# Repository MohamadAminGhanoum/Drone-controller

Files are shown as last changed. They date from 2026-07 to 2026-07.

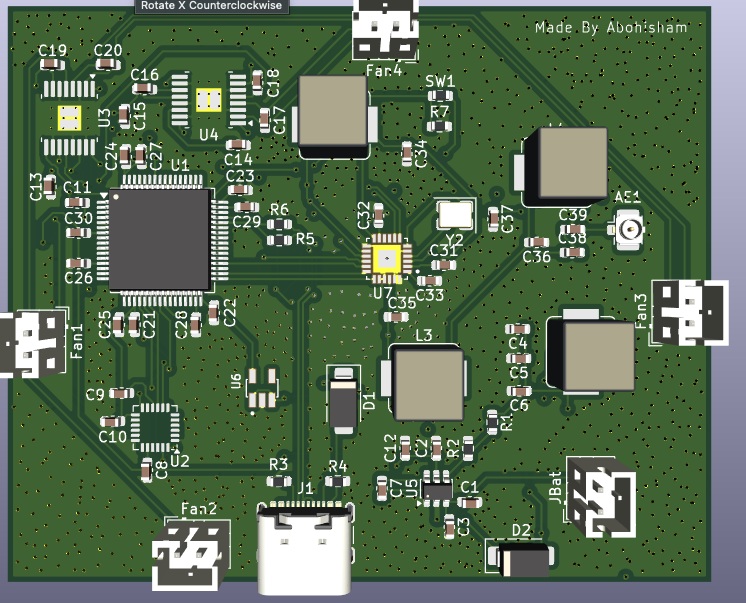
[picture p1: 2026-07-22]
ASSETS_Drone_controller/Screenshot 2026-07-12 at 15.29.26.png

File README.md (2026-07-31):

# Drone-controller
So i have this drone that i have had for a very long time. I recieved it without a controller, so it was basically a uselss drone. I played with it previously and tried to connect all 4 motors to 5v to see if it would fly, but ofc it wouldnt stablilize and all that. Today i know that i need a specific IMU snesor using the gyroscope to determing how the drone is positioned, and then it would send this signal to a chip that would control the current or power recieved by each motor to stabilize the drone. This is what i have planned to make in this project, and it would be slightly more complex than a normal drone controller, as i need to add motor controllers as well because my drone has bruhless motors.

## Schematics for controller:



## Schematics for remote:



## PCB for controller:



## PCB for remote:



## 3d shape for controller:



## 3d shape for remote:


## BOM:

|Nr |Designator |Footprint |Quantity |Cost, usd|Designation |Supplier and ref|Link |
|---|---|---|---|---|---|---|---|
|1  |U1 |LQFP-64_10x10mm_P0.5mm |3 |20.86 |STM32F405RGTx |Lcsc |https://www.lcsc.com/product-detail/C15742.html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 |
|2  |Fan1,2,3,4 |JST_PH_B2B-PH-K_1x02_P2.00mm_Vertical |20 |0.71 |MOTORs |LCSC |https://www.lcsc.com/product-detail/C131337.html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 |
|3  |R5,R6 |R_0603_1608Metric |100 |0.72 |22 |LCSC |https://www.lcsc.com/product-detail/C107701.html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 |
|4  |L2 |L_Bourns_SRP7028A_7.3x6.6mm |10 |0.8 |15uH |LCSC |https://www.lcsc.com/product-detail/C5349699.html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 |
|5  |C3,C32,C10,C17,C30,C18,C21,C23,C20,C9,C29,C26,C22,C19,C7,C24,C25|C_0603_1608Metric |50 |1.27 |0.1uF |LCSC |https://www.lcsc.com/product-detail/C14663.html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 |
|6  |C31,C33 |C_0603_1608Metric |50 |0.8 |10nF |LCSC |https://www.lcsc.com/product-detail/C100042.html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 |
|7  |U7 |XCVR_SX1280IMLTRT |3 |12.71 |SX1280IMLTRT |LCSC |https://www.lcsc.com/product-detail/C125969.html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 |
|8  |C39 |C_0603_1608Metric |50 |0.73 |100pF |LCSC |https://www.lcsc.com/product-detail/C14665.html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 |
|9  |C34 |C_0603_1608Metric |20 |0.62 |470nF |LCSC |https://www.lcsc.com/product-detail/C1623.html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 |
|10 |C2,C1,C12,C15 |C_0603_1608Metric |20 |0.83 |10uF |LCSC |https://www.lcsc.com/product-detail/C19702.html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 |
|11 |C6,C4,C5 |C_0603_1608Metric |5 |0.66 |22uF |LCSC |https://www.lcsc.com/product-detail/C2762594.html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|
|12 |U5 |SOT-23-6 |3 |4 |TPS563200 |LCSC |https://www.lcsc.com/product-detail/C97253.html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 |
|13 |C35 |C_0603_1608Metric |5 |0.76 |0.8pF |LCSC |https://www.lcsc.com/product-detail/C42432054.html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 |
|14 |U4,U3 |HTSSOP-16-1EP_4.4x5mm_P0.65mm_EP3.4x5mm_Mask2.46x2.31mm_ThermalVias|3 |3.27 |DRV8833PWP |LCSC |https://www.lcsc.com/product-detail/C50506.html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 |
|15 |J1 |USB_C_Receptacle_GCT_USB4105-xx-A_16P_TopMnt_Horizontal |2 |0 |USB_C_Receptacle_USB2.0_16P|Selfsourced |previously bought from lcsc |
|16 |C16,C11 |C_0603_1608Metric |50 |0.8 |0.01uF |LCSC |https://www.lcsc.com/product-detail/C100042.html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 |
|17 |C13,C14,C28 |C_0603_1608Metric |50 |1.45 |2.2uF |LCSC |https://www.lcsc.com/product-detail/C23630.html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 |
|18 |R3,R4 |R_0603_1608Metric |100 |0.28 |5.1k |LCSC |https://www.lcsc.com/product-detail/C2907044.html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 |
|19 |R7,R2 |R_0603_1608Metric |100 |0.81 |10k |LCSC |https://www.lcsc.com/product-detail/C844918.html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 |
|21 |C27 |C_0603_1608Metric |50 |1.15 |1uF |LCSC |https://www.lcsc.com/product-detail/C29936.html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 |
|22 |D1,D2 |D_SMA |50 |0.73 |SS14 |LCSC |https://www.lcsc.com/product-detail/C2837270.html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 |
|23 |C38 |C_0603_1608Metric |100 |0.72 |0.5pF |LCSC |https://www.lcsc.com/product-detail/C1633.html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 |
|24 |Y2 |Crystal_SMD_3225-4Pin_3.2x2.5mm |5 |0.51 |52mhz |LCSC |https://www.lcsc.com/product-detail/C3034316.html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 |
|25 |AE1 |U.FL_Hirose_U.FL-R-SMT-1_Vertical |1 |N/A |Antenna |N/A |https://www.lcsc.com/product-detail/C88374.html |
|26 |JBat |JST_PH_B2B-PH-K_1x02_P2.00mm_Vertical |20 |0.71 |Battery_connector |LCSC |https://www.lcsc.com/product-detail/C131337.html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 |
|27 |L1 |L_Bourns_SRP7028A_7.3x6.6mm |10 |0.7 |3.3uH |LCSC |https://www.lcsc.com/product-detail/C5349703.html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 |
|28 |R1 |R_0603_1608Metric |100 |0.32 |54.9k |LCSC |https://www.lcsc.com/product-detail/C23077.html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 |
|29 |SW1 |R_0603_1608Metric |1 |0 |SW_Push |Selfsourced |previously bought from lcsc |
|30 |U6 |SOT95P285X140-5N |5 |0.79 |AP2112K-3.3TRG1 |LCSC |https://www.lcsc.com/product-detail/C51118.html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 |
|31 |U2 |InvenSense_QFN-24_4x4mm_P0.5mm |2 |29.24 |MPU-6000 |LCSC |https://www.lcsc.com/product-detail/C92401.html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 |
|32 |C8 |C_0603_1608Metric |50 |0.63 |2.2nF |LCSC |https://www.lcsc.com/product-detail/C16033.html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 |
|33 |C37,C36 |C_0603_1608Metric |100 |0.68 |1.2pF |LCSC |https://www.lcsc.com/product-detail/C519098.html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|
|34 |PCB |Remote controller |5 |7 |N/A |Jlcpcb |N/A |
|35 |PCB |Drone controller |5 |7 |N/A |Jlcpcb |N/A |
|36 |AE1 |Antenna |2 |6.43 |N/A |LCSC |https://www.lcsc.com/product-detail/C3285086.html |
|37 |C |C_0603_1608Metric |50 |0.7 |15pf |LCSC |https://www.lcsc.com/product-detail/C1644.html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 |
| | | | | | | | |
| | | |Total price w. tax & ship|150.69 | | | |

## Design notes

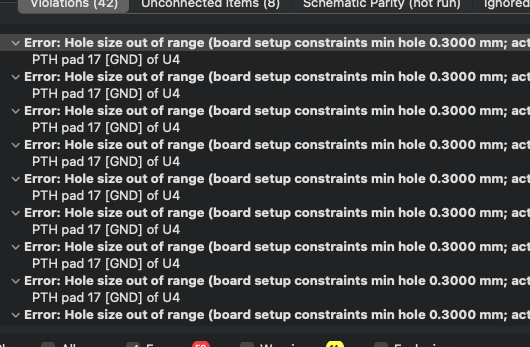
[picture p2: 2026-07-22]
ASSETS_Drone_controller/Screenshot 2026-07-12 at 12.57.38.png

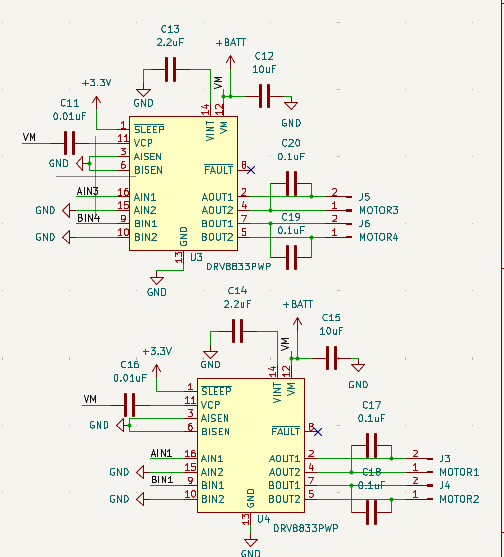
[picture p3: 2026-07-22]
ASSETS_Drone_controller/Screenshot 2026-07-10 at 17.01.51.png

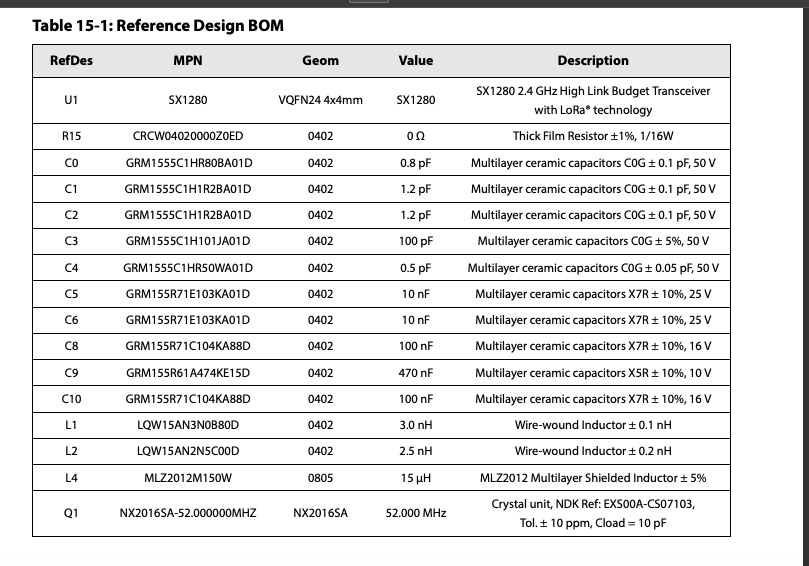
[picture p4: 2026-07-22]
ASSETS_Drone_controller/Screenshot 2026-07-10 at 17.49.38.png

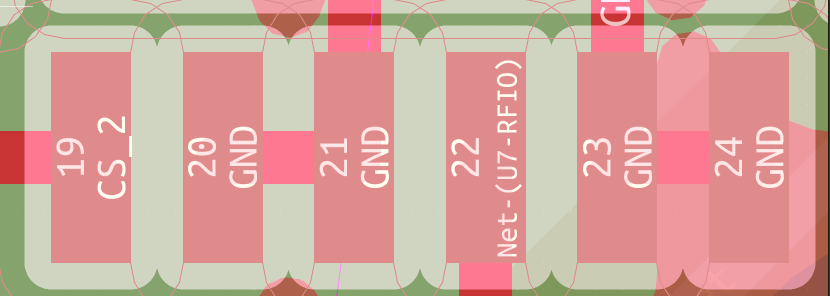
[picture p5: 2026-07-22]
ASSETS_Drone_controller/Screenshot 2026-07-12 at 13.29.08.png

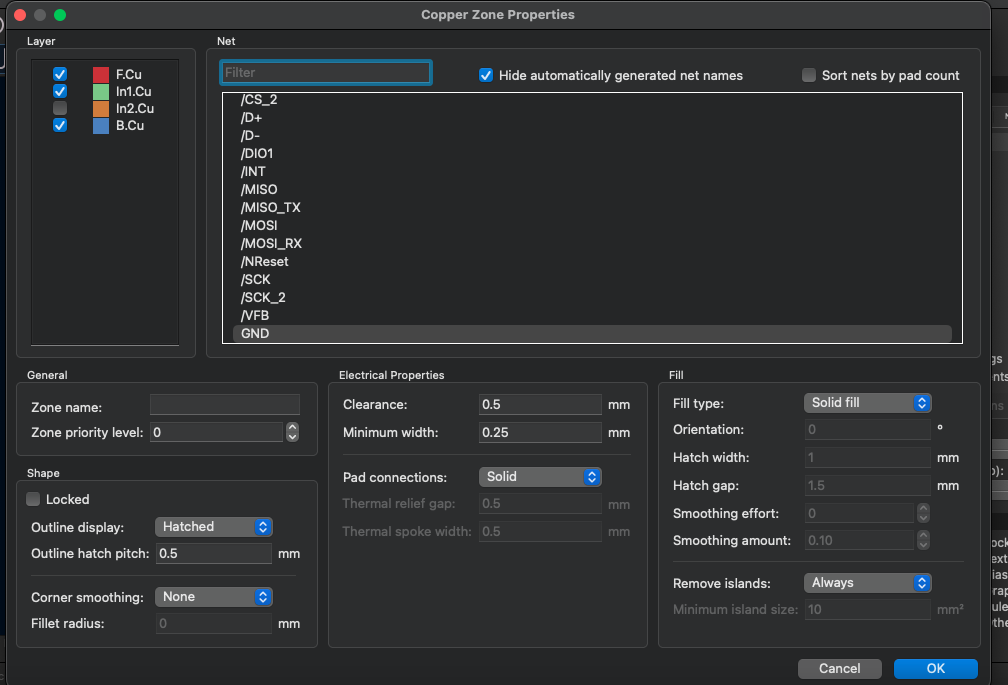
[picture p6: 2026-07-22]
ASSETS_Drone_controller/Screenshot 2026-07-12 at 12.56.29.png

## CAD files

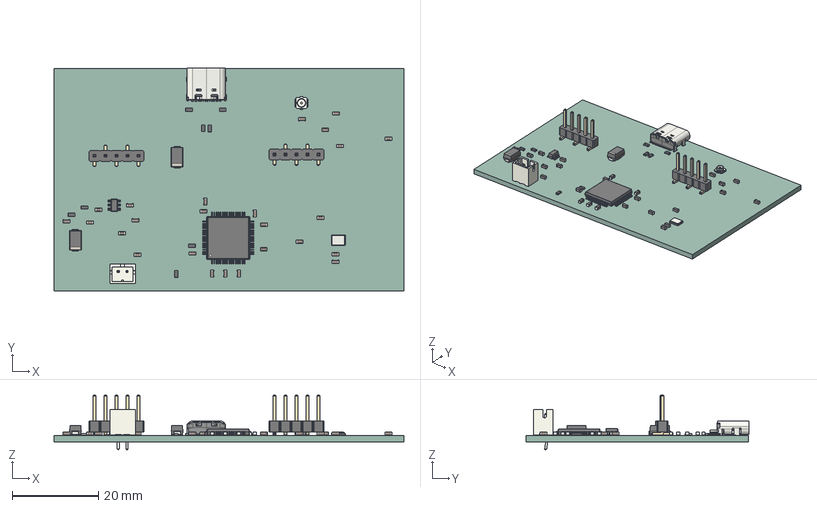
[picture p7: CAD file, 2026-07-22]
ASSETS_Drone_controller/Remote control.step
81.1 x 51.6 x 12.7 mm
Crystal_SMD_3225-4Pin_3.2x2.5mm
R_0603_1608Metric x 8
C_0603_1608Metric x 25
D_SMA x 2
PinHeader_1x05_P2.54mm_Vertical_SMD_Pin1Left
JST_PH_B2B-PH-K_1x02_P2.00mm_Vertical
LQFP-64_10x10mm_P0.5mm
USB_C_Receptacle_GCT_USB4105-xx-A_16P_TopMnt_Horizontal
U.FL_Hirose_U.FL-R-SMT-1_Vertical
SOT-23-6
PinHeader_1x05_P2.54mm_Vertical_SMD_Pin1Right
Remote control_PCB

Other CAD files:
CAD/Remote control CAD.step
CAD/Remote control CAD.f3z

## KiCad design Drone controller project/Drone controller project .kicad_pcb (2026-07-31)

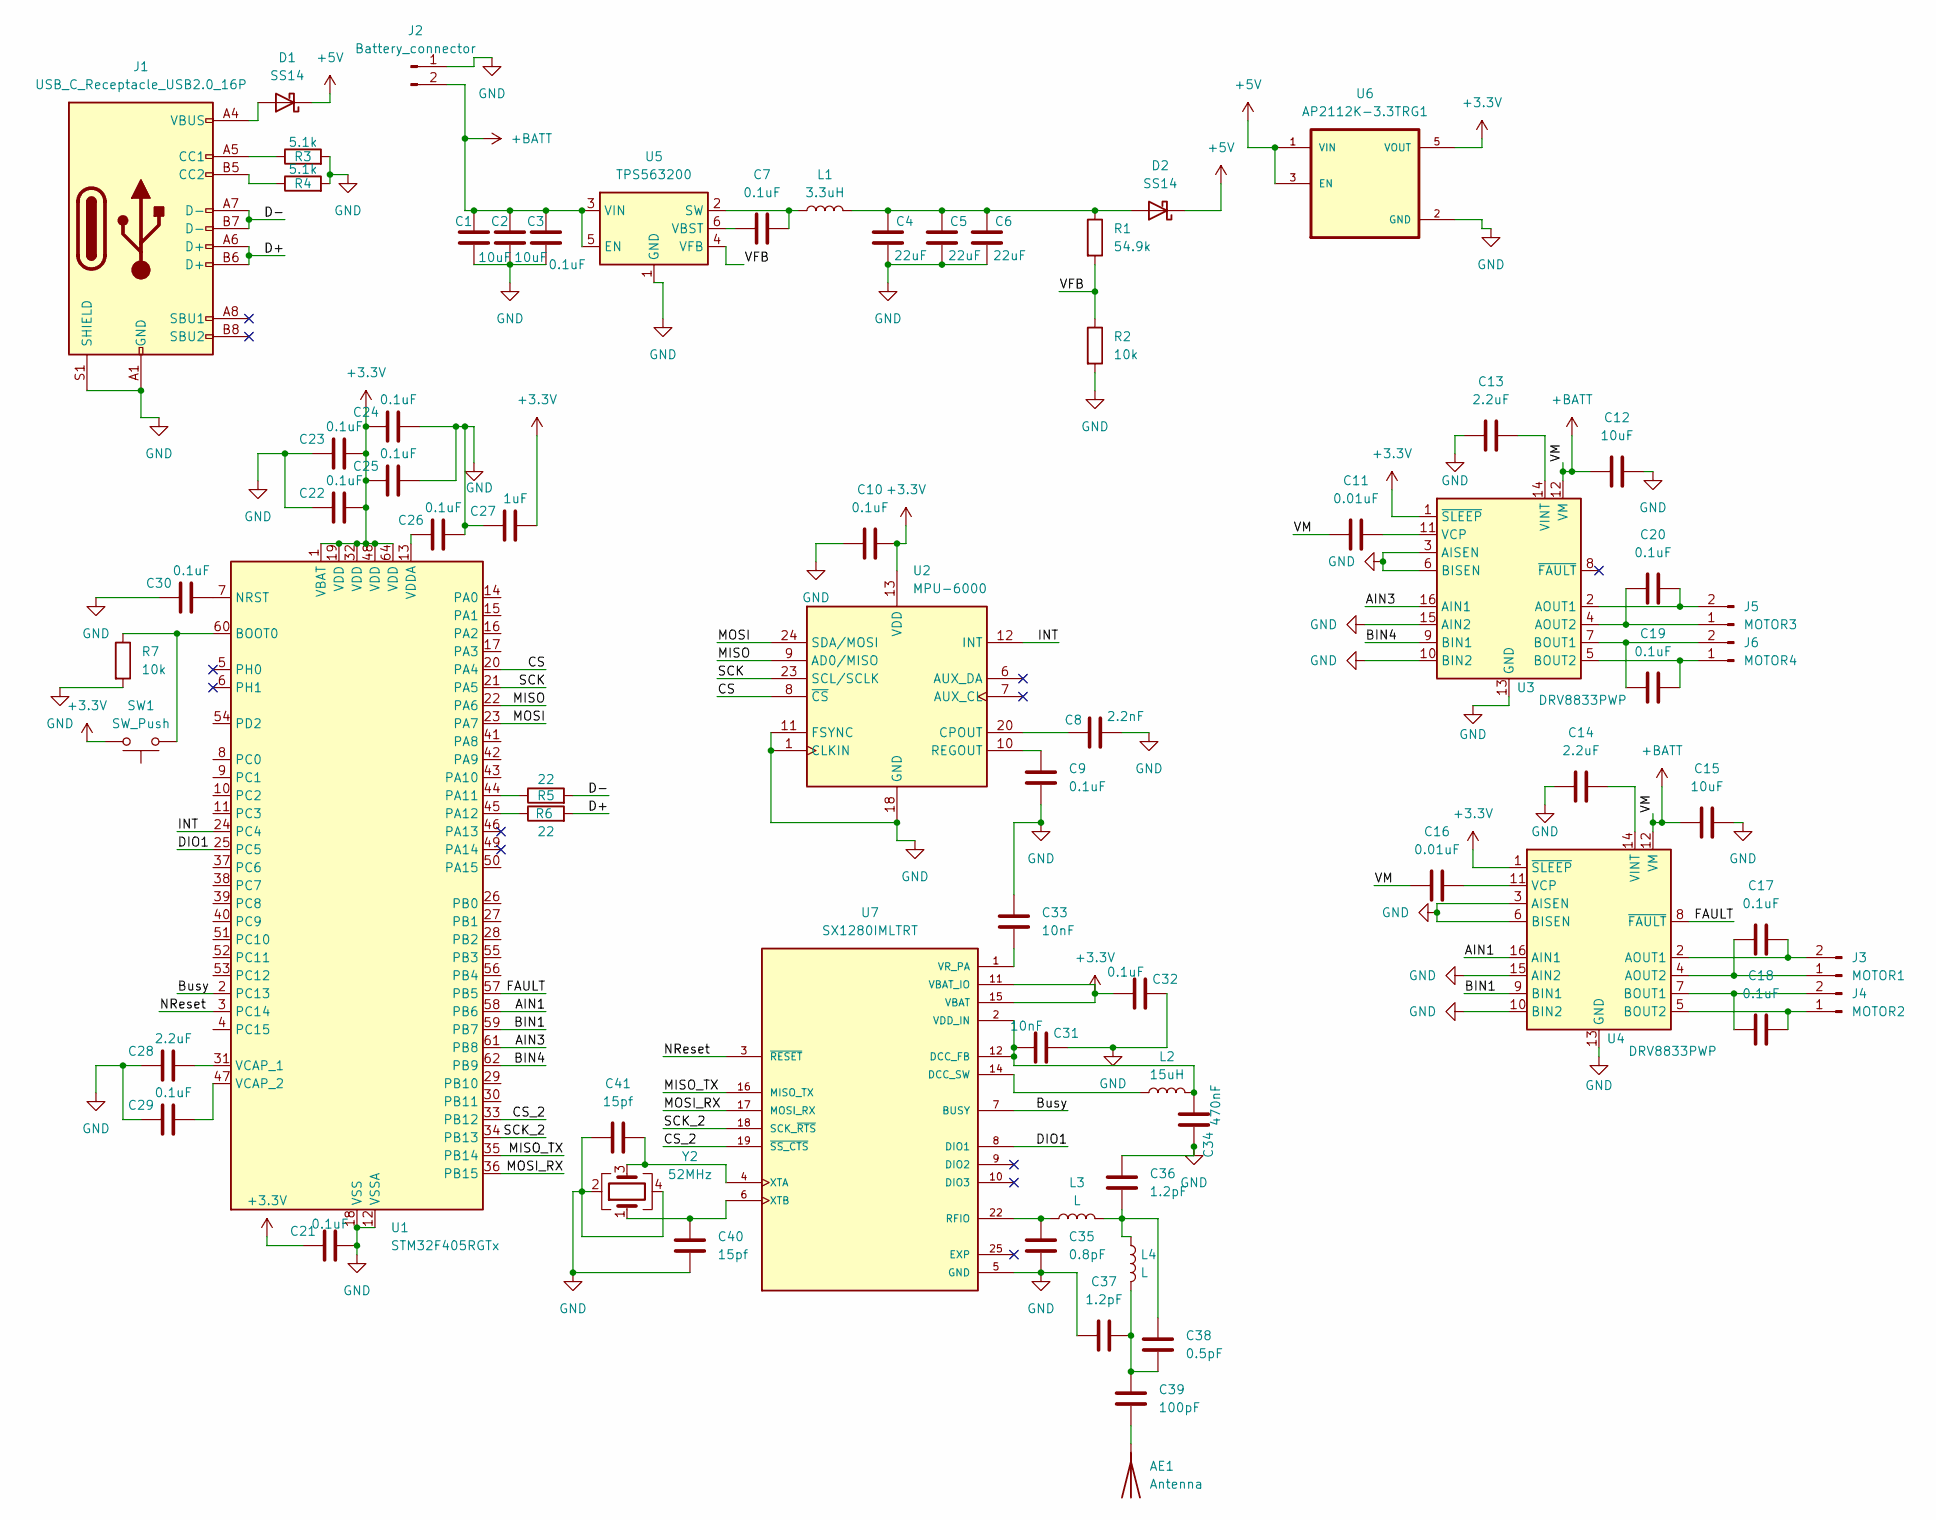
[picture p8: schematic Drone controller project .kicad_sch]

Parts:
AE1: Antenna; U.FL_Hirose_U.FL-R-SMT-1_Vertical
C1, C2, C12, C15: 10uF; C_0603_1608Metric
C3, C7, C9, C10, C17, C18, C19, C20, C21, C22, C23, C24, C25, C26, C29, C30, C32: 0.1uF; C_0603_1608Metric
C4, C5, C6: 22uF; C_0603_1608Metric
C8: 2.2nF; C_0603_1608Metric
C11, C16: 0.01uF; C_0603_1608Metric
C13, C14, C28: 2.2uF; C_0603_1608Metric
C27: 1uF; C_0603_1608Metric
C31, C33: 10nF; C_0603_1608Metric
C34: 470nF; C_0603_1608Metric
C35: 0.8pF; C_0603_1608Metric
C36, C37: 1.2pF; C_0603_1608Metric
C38: 0.5pF; C_0603_1608Metric
C39: 100pF; C_0603_1608Metric
C40, C41: 15pf; C_0603_1608Metric
D1, D2: SS14; D_SMA
J1: USB_C_Receptacle_USB2.0_16P; USB_C_Receptacle_GCT_USB4105-xx-A_16P_TopMnt_Horizontal
J2: Battery_connector; JST_PH_B2B-PH-K_1x02_P2.00mm_Vertical
J3: MOTOR1; JST_PH_B2B-PH-K_1x02_P2.00mm_Vertical
J4: MOTOR2; JST_PH_B2B-PH-K_1x02_P2.00mm_Vertical
J5: MOTOR3; JST_PH_B2B-PH-K_1x02_P2.00mm_Vertical
J6: MOTOR4; JST_PH_B2B-PH-K_1x02_P2.00mm_Vertical
L1: 3.3uH; L_Bourns_SRP7028A_7.3x6.6mm
L2: 15uH; L_Bourns_SRP7028A_7.3x6.6mm
L3, L4: L; L_Bourns_SRP7028A_7.3x6.6mm
R1: 54.9k; R_0603_1608Metric
R2, R7: 10k; R_0603_1608Metric
R3, R4: 5.1k; R_0603_1608Metric
R5, R6: 22; R_0603_1608Metric
SW1: SW_Push; R_0603_1608Metric
U1: STM32F405RGTx; LQFP-64_10x10mm_P0.5mm
U2: MPU-6000; InvenSense_QFN-24_4x4mm_P0.5mm
U3, U4: DRV8833PWP; HTSSOP-16-1EP_4.4x5mm_P0.65mm_EP3.4x5mm_Mask2.46x2.31mm_The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
U5: TPS563200; SOT-23-6
U6: AP2112K-3.3TRG1; SOT95P285X140-5N; PARTREV 2-2
U7: SX1280IMLTRT; XCVR_SX1280IMLTRT; PARTREV 3.3
Y2: 52MHz; Crystal_SMD_3225-4Pin_3.2x2.5mm

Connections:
+3.3V: C10.2, C21.1, C22.2, C23.2, C24.1, C25.1, C27.2, C32.1, SW1.2, U1.1 (VBAT), U1.19 (VDD), U1.32 (VDD), U1.48 (VDD), U1.64 (VDD), U2.13 (VDD), U3.1 (~SLEEP), U4.1 (~SLEEP), U6.5 (VOUT), U7.11 (VBAT_IO), U7.15 (VBAT)
+5V: D1.1 (K), D2.1 (K), U6.1 (VIN), U6.3 (EN)
+BATT: C1.1, C2.1, C3.1, C11.1, C12.1, C15.1, C16.1, J2.2, U3.12 (VM), U4.12 (VM), U5.3 (VIN), U5.5 (EN)
/AIN1: U1.58 (PB6), U4.16 (AIN1)
/AIN3: U1.61 (PB8), U3.16 (AIN1)
/BIN1: U1.59 (PB7), U4.9 (BIN1)
/BIN4: U1.62 (PB9), U3.9 (BIN1)
/Busy: U1.2 (PC13), U7.7 (BUSY)
/CS: U1.20 (PA4), U2.8 (~CS)
/CS_2: U1.33 (PB12), U7.19 (~SS_CTS)
/D+: J1.A6 (D+), J1.B6 (D+), R6.2
/D-: J1.A7 (D-), J1.B7 (D-), R5.2
/DIO1: U1.25 (PC5), U7.8 (DIO1)
/FAULT: U1.57 (PB5), U4.8 (~FAULT)
/INT: U1.24 (PC4), U2.12 (INT)
/MISO: U1.22 (PA6), U2.9 (AD0/MISO)
/MISO_TX: U1.35 (PB14), U7.16 (MISO_TX)
/MOSI: U1.23 (PA7), U2.24 (SDA/MOSI)
/MOSI_RX: U1.36 (PB15), U7.17 (MOSI_RX)
/NReset: U1.3 (PC14), U7.3 (~RESET)
/SCK: U1.21 (PA5), U2.23 (SCL/SCLK)
/SCK_2: U1.34 (PB13), U7.18 (SCK_~RTS)
/VFB: R1.2, R2.1, U5.4 (VFB)
GND: C1.2, C2.2, C3.2, C4.2, C5.2, C6.2, C8.2, C9.2, C10.1, C12.2, C13.1, C14.1, C15.2, C21.2, C22.1, C23.1, C24.2, C25.2, C26.2, C27.1, C28.1, C29.1, C30.1, C31.2, C32.2, C33.1, C34.2, C35.2, C36.1, C37.2, C40.2, C41.1, J1.A1 (GND), J1.A12 (GND), J1.B1 (GND), J1.B12 (GND), J1.S1 (SHIELD), J2.1, R2.2, R3.2, R4.2, R7.2, U1.12 (VSSA), U1.18 (VSS), U1.63 (VSS), U2.1 (CLKIN), U2.11 (FSYNC), U2.18 (GND), U3.3 (AISEN), U3.6 (BISEN), U3.10 (BIN2), U3.13 (GND), U3.15 (AIN2), U3.17 (GND), U4.3 (AISEN), U4.6 (BISEN), U4.10 (BIN2), U4.13 (GND), U4.15 (AIN2), U4.17 (GND), U5.1 (GND), U6.2 (GND), U7.5 (GND), U7.13 (GND), U7.20 (GND), U7.21 (GND), U7.23 (GND), U7.24 (GND), Y2.2, Y2.4
unnamed: AE1.1 (A), C39.2
unnamed: C36.2, C38.1, L3.2, L4.1
unnamed: C37.1, C38.2, C39.1, L4.2
unnamed: D1.2 (A), J1.A4 (VBUS), J1.A9 (VBUS), J1.B4 (VBUS), J1.B9 (VBUS)
unnamed: C4.1, C5.1, C6.1, D2.2 (A), L1.2, R1.1
unnamed: J1.A5 (CC1), R3.1
unnamed: J1.B5 (CC2), R4.1
unnamed: C17.1, J3.1, U4.4 (AOUT2)
unnamed: C17.2, J3.2, U4.2 (AOUT1)
unnamed: C18.1, J4.1, U4.5 (BOUT2)
unnamed: C18.2, J4.2, U4.7 (BOUT1)
unnamed: C20.1, J5.1, U3.4 (AOUT2)
unnamed: C20.2, J5.2, U3.2 (AOUT1)
unnamed: C19.2, J6.1, U3.5 (BOUT2)
unnamed: C19.1, J6.2, U3.7 (BOUT1)
unnamed: R7.1, SW1.1, U1.60 (BOOT0)
unnamed: C30.2, U1.7 (NRST)
unnamed: R5.1, U1.44 (PA11)
unnamed: R6.1, U1.45 (PA12)
unnamed: C28.2, U1.31 (VCAP_1)
unnamed: C29.2, U1.47 (VCAP_2)
unnamed: C26.1, U1.13 (VDDA)
unnamed: C8.1, U2.20 (CPOUT)
unnamed: C9.1, U2.10 (REGOUT)
unnamed: C11.2, U3.11 (VCP)
unnamed: C13.2, U3.14 (VINT)
unnamed: C16.2, U4.11 (VCP)
unnamed: C14.2, U4.14 (VINT)
unnamed: C7.2, L1.1, U5.2 (SW)
unnamed: C7.1, U5.6 (VBST)
unnamed: C31.1, C34.1, L2.2, U7.2 (VDD_IN), U7.12 (DCC_FB)
unnamed: L2.1, U7.14 (DCC_SW)
unnamed: C35.1, L3.1, U7.22 (RFIO)
unnamed: C33.2, U7.1 (VR_PA)
unnamed: C41.2, U7.4 (XTA), Y2.3
unnamed: C40.1, U7.6 (XTB), Y2.1

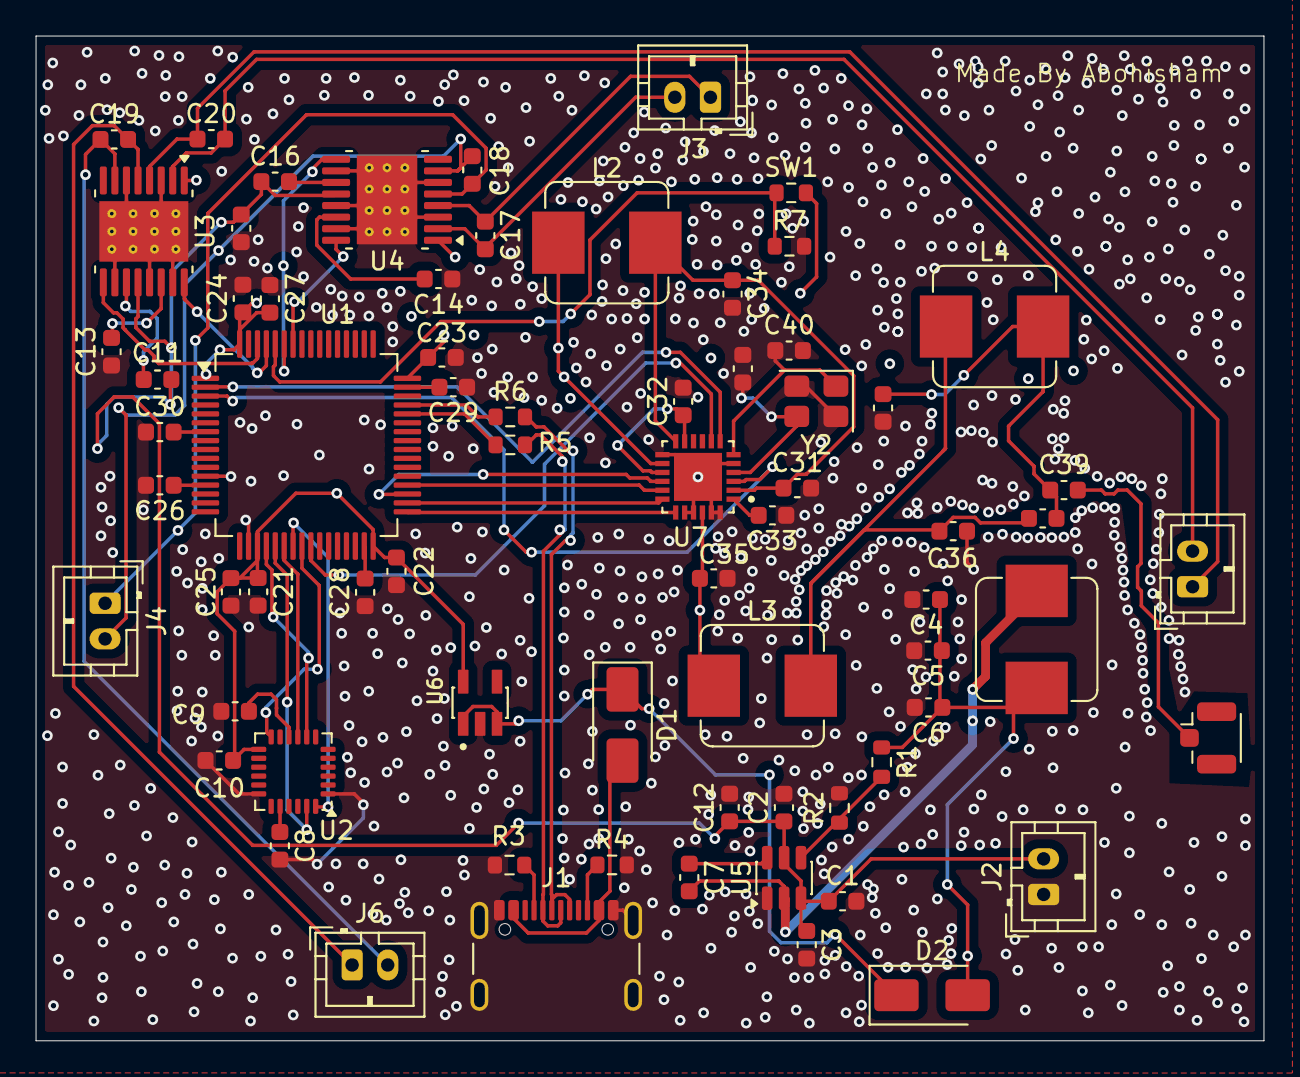
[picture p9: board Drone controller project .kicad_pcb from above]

Board: 4 copper layers, 69.0 x 56.4 mm, 70 parts (0 on the bottom side), 60 nets.

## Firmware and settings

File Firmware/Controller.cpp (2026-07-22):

#include <SPI.h>
#include <nRF24L01.h>
#include <RF24.h>
#include <Servo.h> 

RF24 radio(7, 8); 
const byte address[6] = "00001";

struct DataPacket {
  byte throttle;
  byte yaw;
  byte pitch;
  byte roll;
};

DataPacket data;

Servo esc1, esc2, esc3, esc4; 

void setup() {
  Serial.begin(9600);
  
  radio.begin();
  radio.openReadingPipe(0, address);
  radio.setPALevel(RF24_PA_HIGH);
  radio.startListening(); 

  esc1.attach(3); 
  esc2.attach(5);
  esc3.attach(6); 
  esc4.attach(9); 

  data.throttle = 0;
  data.yaw = 127;
  data.pitch = 127;
  data.roll = 127;
  
  writeToESCs(1000, 1000, 1000, 1000);
  delay(3000); 
}

void loop() {
  if (radio.available()) {
    radio.read(&data, sizeof(DataPacket));
  }

  int baseThrottle = map(data.throttle, 0, 255, 1000, 2000);
  
  if (baseThrottle < 1050) {
    writeToESCs(1000, 1000, 1000, 1000);
  } else {
    
    writeToESCs(baseThrottle, baseThrottle, baseThrottle, baseThrottle);
  }
}

void writeToESCs(int m1, int m2, int m3, int m4) {
  esc1.writeMicroseconds(m1);
  esc2.writeMicroseconds(m2);
  esc3.writeMicroseconds(m3);
  esc4.writeMicroseconds(m4);
}

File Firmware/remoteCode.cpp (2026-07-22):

#include <SPI.h>
#include <nRF24L01.h>
#include <RF24.h>

RF24 radio(7, 8); 
const byte address[6] = "00001";

struct DataPacket {
  byte throttle;
  byte yaw;
  byte pitch;
  byte roll;
};

DataPacket data;

void setup() {
  radio.begin();
  radio.openWritingPipe(address);
  radio.setPALevel(RF24_PA_HIGH); 
  radio.stopListening(); 
  
  data.throttle = 0;
  data.yaw = 127;
  data.pitch = 127;
  data.roll = 127;
}

void loop() {
  data.throttle = map(analogRead(A0), 0, 1023, 0, 255);
  data.yaw      = map(analogRead(A1), 0, 1023, 0, 255);
  data.pitch    = map(analogRead(A2), 0, 1023, 0, 255);
  data.roll     = map(analogRead(A3), 0, 1023, 0, 255);

  radio.write(&data, sizeof(DataPacket));
  
  delay(20); 
}

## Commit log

2026-07-12 Update README with project details and visuals
    Expanded project description and added sections for schematics, PCB, 3D shape, and BOM.
2026-07-22 Add CAD files
    [Remote control CAD.f3z, Remote control CAD.step]
2026-07-22 Rename Remote control CAD.f3z to CAD/Remote control CAD.f3z
    [Remote control CAD.f3z]
2026-07-22 Rename Remote control CAD.step to CAD/Remote control CAD.step
    [Remote control CAD.step]
2026-07-22 Add Controller.cpp for ESC control via RF
    Implement radio control for ESCs with data packet structure.
